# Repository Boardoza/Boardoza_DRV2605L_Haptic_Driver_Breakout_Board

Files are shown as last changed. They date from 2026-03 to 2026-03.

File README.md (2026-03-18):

# Boardoza DRV2605L Haptic Motor Driver Breakout Board

The **Boardoza DRV2605L Haptic Driver Breakout Board** is based on the **Texas Instruments DRV2605L**, a powerful and intelligent haptic motor driver designed specifically for **ERM (Eccentric Rotating Mass)** and **LRA (Linear Resonant Actuator)** vibration motors. Unlike simple on/off motor drivers, the DRV2605L integrates a built-in waveform library and smart-loop control engine to generate advanced vibration effects such as clicks, double-clicks, ramps, buzz patterns, and audio-synchronized feedback.

Unlike standard motor drivers for DC or stepper motors, the DRV2605 is optimized for **ERM (Eccentric Rotating Mass)** and **LRA (Linear Resonant Actuator)** motors. It communicates via **I²C**, allowing you to configure, chain, and trigger complex vibration patterns directly from your microcontroller. This breakout board is ideal for **wearables, game controllers, touch interfaces, mobile devices, assistive systems, and any project that requires professional-grade haptic feedback**.

## [Click here to purchase!](https://www.ozdisan.com/ureticiler/boardoza)

| Front Side | Back Side |
|:---:|:---:|
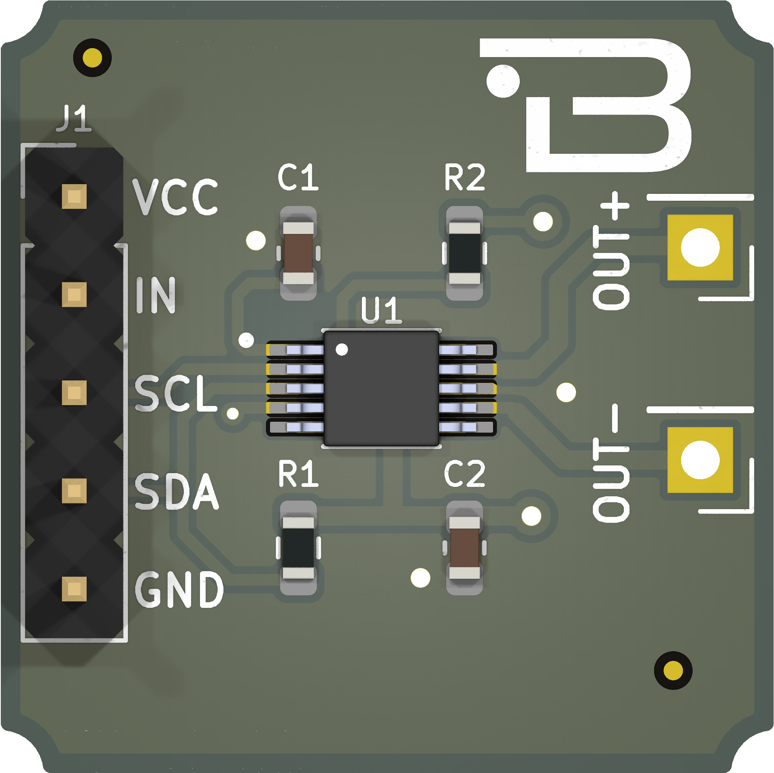
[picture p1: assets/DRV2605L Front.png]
DRV2605L Front
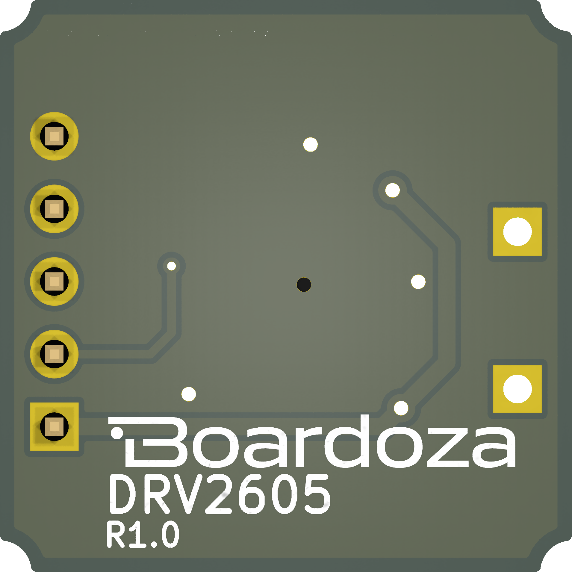
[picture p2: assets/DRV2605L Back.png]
DRV2605L Back
|  |  |

---

## Key Features
 
- **I²C-Controlled Digital Playback Engine:** Includes a waveform sequencer for flexible haptic pattern generation.  
- **Real-Time Playback Options:** Supports control via I²C, PWM, or analog input.  
- **Dual Drive Modes:** Operates in open-loop (ERM) and closed-loop (LRA) configurations.  
- **Smart-Loop™ Control:** Provides automatic overdrive and braking for optimized performance.  
- **Automatic Resonance Tracking:** Includes actuator diagnostics for LRA operation.  
- **Automatic Level Calibration:** Ensures consistent output performance.  
- **Battery Voltage Compensation:** Maintains stable operation under varying supply conditions.  
- **Differential H-Bridge Output:** Features OUT+ and OUT− for driving actuators.    

---

## Technical Specifications

**Model:** DRV2605L  
**Manufacturer:** Boardoza  
**Manufacturer IC:** Texas Instruments  
**Device Type:** Haptic Driver IC  
**Functions:** Smart Haptic Motor Driver    
**Input Voltage (VDD):** 2.0V – 5.2V  
**Interface:** I²C (Standard & Fast Mode, up to 400kHz)  
**Control Input (IN/TRIG):** PWM / Analog / External Trigger (Selectable)  
**Supported Actuators:**  
- ERM (Eccentric Rotating Mass) – Open-Loop Drive  
- LRA (Linear Resonant Actuator) – Closed-Loop with Auto Resonance Tracking  

**Playback Modes:**  
- Internal ROM Waveform Library  
- RAM-Based Custom Waveform Sequencing  
- Real-Time Playback (RTP) Mode  
- Audio-to-Vibe Mode  

**Drive Output:** Differential H-Bridge (OUT+, OUT−)  
**Auto Features:**  
- Automatic Overdrive & Braking  
- Automatic Resonance Tracking (LRA)  
- Automatic Level Calibration  
- Actuator Diagnostics  

**Operating Temperature:** -40°C to +150°C  
**Board Dimensions:** 20mm x 20mm   

---

## Board Pinout

### ( J1 ) Control & Power Connector

| Pin Number | Pin Name | Description |
|:---:|:---:|---|
| 1 | VCC | Supply Input (2.0V – 5.2V DC) |
| 2 | IN | Multi-mode Input (PWM / Analog / Trigger). Connect to GND if unused |
| 3 | SCL | I²C Serial Clock |
| 4 | SDA | I²C Serial Data |
| 5 | GND | Ground |

### ( J2 ) Haptic Motor Output

| Pin Number | Pin Name | Description |
|:---:|:---:|---|
| 1 | OUT+ | Positive Differential Output |
| 2 | OUT− | Negative Differential Output |

---

## Board Dimensions

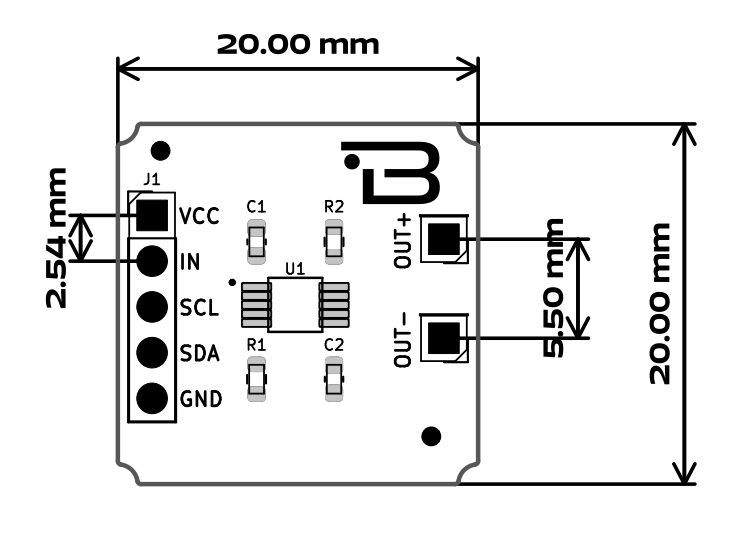
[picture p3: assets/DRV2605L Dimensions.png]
DRV2605L Board Dimension


---

## Step Files

[Boardoza DRV2605L.step](./assets/DRV2605L%20Step.step)

---

## Datasheet

[DRV2605L Datasheet.pdf](./assets/DRV2605L%20Datasheet.pdf)

---

## Version History

- V1.0.0 - Initial Release  

---

## Support

- If you have any questions or need support, please contact **support@boardoza.com**

---

## **License**

This repository contains both hardware and software components:

### **Hardware Design**

[][cc-by-sa]

All hardware design files are licensed under [Creative Commons Attribution-ShareAlike 4.0 International License][cc-by-sa].

[cc-by-sa]: http://creativecommons.org/licenses/by-sa/4.0/
[cc-by-sa-shield]: https://img.shields.io/badge/License-CC%20BY--SA%204.0-lightgrey.svg

### **Software/Firmware**

[][bsd]

All software and firmware are licensed under [BSD 3-Clause License][bsd].

[bsd]: https://opensource.org/licenses/BSD-3-Clause
[bsd-shield]: https://img.shields.io/badge/License-BSD%203--Clause-blue.svg

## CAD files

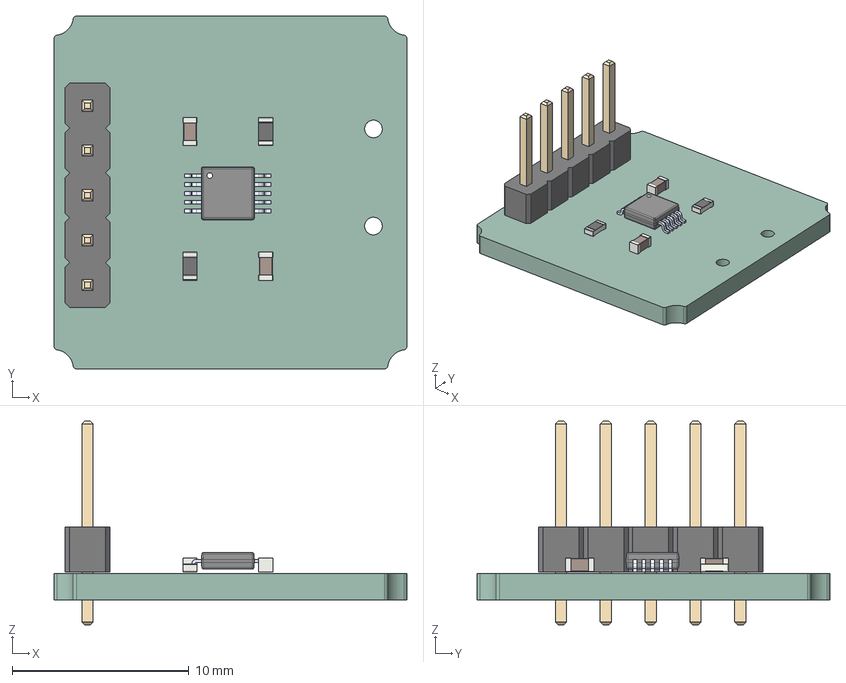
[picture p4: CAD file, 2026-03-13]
assets/DRV2605L Step.step
20.0 x 20.0 x 11.5 mm
PinHeader_1x05_P2.54mm_Vertical
R_0603_1608Metric x 2
C_0603_1608Metric x 2
DRV2605LDGSR
B-DRV2605L-BRK_PCB

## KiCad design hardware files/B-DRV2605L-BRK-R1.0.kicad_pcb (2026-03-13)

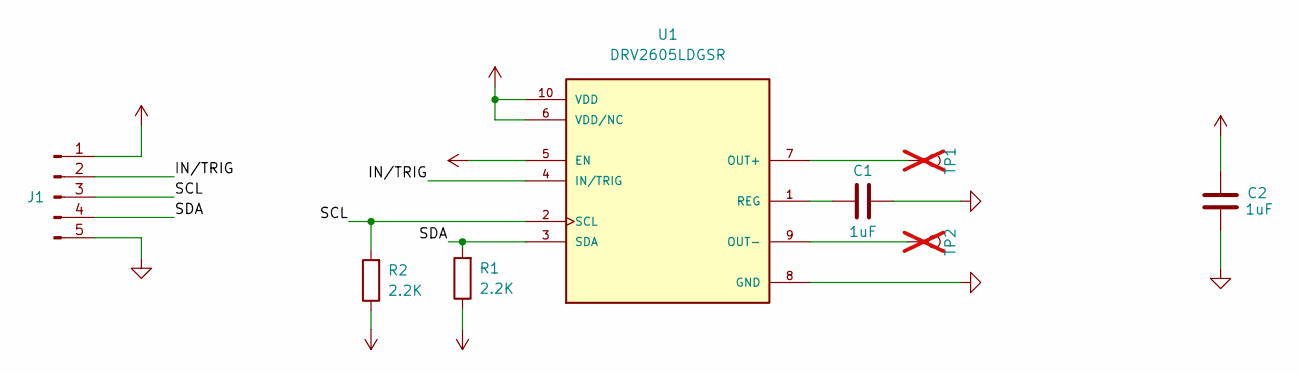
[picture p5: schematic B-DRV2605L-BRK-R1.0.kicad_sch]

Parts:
C1, C2: 1uF; C_0603_1608Metric; MPN CL10A105KO8NNNC
J1: Conn_01x05_Pin; PinHeader_1x05_P2.54mm_Vertical; MPN 5PH1SDA25-105G0NNBL-3X6
R1, R2: 2.2K; R_0603_1608Metric; MPN CRT03F7E2201
TP1, TP2: TestPoint; PinHeader_1x01_P2.54mm_Vertical; not fitted
U1: DRV2605LDGSR; SOP50P490X110-10N; PARTREV D

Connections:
/IN/TRIG: J1.2, U1.4 (IN/TRIG)
/SCL: J1.3, R2.2, U1.2 (SCL)
/SDA: J1.4, R1.2, U1.3 (SDA)
GND: C1.2, C2.1, J1.5, U1.8 (GND)
unnamed: TP1.1, U1.7 (OUT+)
unnamed: TP2.1, U1.9 (OUT-)
unnamed: C1.1, U1.1 (REG)
VCC: C2.2, J1.1, R1.1, R2.1, U1.5 (EN), U1.6 (VDD/NC), U1.10 (VDD)

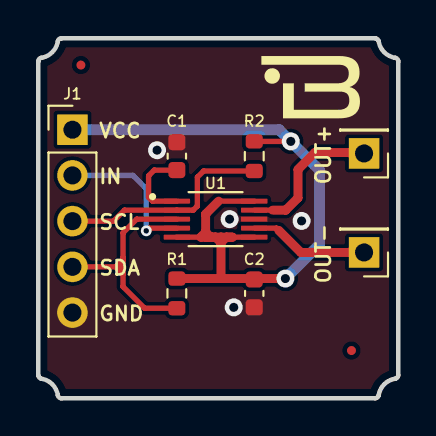
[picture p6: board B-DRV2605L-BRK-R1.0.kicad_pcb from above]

Board: 2 copper layers, 20.0 x 20.0 mm, 8 parts (0 on the bottom side), 8 nets.

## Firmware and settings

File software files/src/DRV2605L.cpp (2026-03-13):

#include "DRV2605L.h"

/**
 * @brief Default constructor for the DRV2605L class.
 *
 * Initializes the I2C address with the default DRV2605L I2C address
 * and sets the I2C interface pointer to nullptr.
 */
DRV2605L::DRV2605L() {
  _i2c = nullptr;
  _i2cAddr = DRV2605L_I2C_ADDR;
}

/**
 * @brief Initializes the DRV2605L device.
 *
 * This function initializes the I2C communication with the specified I2C interface
 * and sets the device's I2C address. It also performs basic setup such as
 * reading the status register, setting the mode to auto-calibration, and 
 * selecting the waveform library.
 *
 * @param wirePort Reference to the TwoWire I2C object (Wire or Wire1).
 * @param i2cAddr  The I2C address of the DRV2605L device.
 * @return true if initialization is successful.
 */
bool DRV2605L::begin(TwoWire &wirePort, uint8_t i2cAddr) {
  _i2c = &wirePort;
  _i2cAddr = i2cAddr;

  _i2c->begin();

  uint8_t status = readRegister8(DRV2605L_REG_STATUS);

  writeRegister8(DRV2605L_REG_MODE, DRV2605L_MODE_AUTOCAL);

  writeRegister8(DRV2605L_REG_LIBRARY, 0x06);

  return true;
}

/**
 * @brief Sets the operating mode of the DRV2605L.
 *
 * The DRV2605L supports multiple modes such as standby, real-time playback, 
 * and auto-calibration. This function sets the mode by writing to the mode register.
 *
 * @param mode The desired operating mode (0-7).
 */
void DRV2605L::setMode(uint8_t mode) {
  writeRegister8(DRV2605L_REG_MODE, mode & 0x07);
}

/**
 * @brief Writes an 8-bit value to a specified register of the DRV2605L.
 *
 * This function sends a command via I2C to write a given value to a specific 
 * register of the DRV2605L haptic driver.
 *
 * @param reg The register address to write to.
 * @param val The 8-bit value to be written to the register.
 */
void DRV2605L::writeRegister8(uint8_t reg, uint8_t val) {
  _i2c->beginTransmission(_i2cAddr);
  _i2c->write(reg);
  _i2c->write(val);
  _i2c->endTransmission();
}

/**
 * @brief Reads an 8-bit value from a specified register of the DRV2605L.
 *
 * This function requests a single byte from the specified register
 * of the DRV2605L over the I2C bus.
 *
 * @param reg The register address to read from.
 * @return The 8-bit value read from the register. Returns 0 if no data is available.
 */
uint8_t DRV2605L::readRegister8(uint8_t reg) {
  _i2c->beginTransmission(_i2cAddr);
  _i2c->write(reg);
  _i2c->endTransmission(false);

  _i2c->requestFrom((int)_i2cAddr, 1);
  if (_i2c->available()) {
    return _i2c->read();
  }
  return 0;
}

/**
 * @brief Sets a waveform sequence slot in the DRV2605L.
 *
 * The DRV2605L supports up to 8 waveform slots, each storing a waveform effect. 
 * This function assigns a waveform to a specific slot, defining the sequence 
 * of haptic effects to be played.
 *
 * @param slot The waveform sequence slot (1-8).
 * @param waveform The waveform ID to assign to the slot.
 */
void DRV2605L::setWaveform(uint8_t slot, uint8_t waveform) {
  // slot = 1 -> 0x04 (WAVESEQ1)
  // slot = 2 -> 0x05 (WAVESEQ2), vb.
  // Basitçe: 0x04 + (slot - 1)
  if(slot < 1) slot = 1;
  if(slot > 8) slot = 8; // Maksimum 8 slot var
  writeRegister8(DRV2605L_REG_WAVESEQ1 + slot - 1, waveform);
}

/**
 * @brief Starts haptic playback.
 *
 * This function sets the GO bit (bit 0) in the DRV2605L control register
 * to initiate haptic playback using the configured waveform sequence.
 */
void DRV2605L::go() {
  writeRegister8(DRV2605L_REG_GO, 0x01);
}

/**
 * @brief Stops haptic playback.
 *
 * This function clears the GO bit (bit 0) in the DRV2605L control register,
 * stopping any currently playing haptic effects.
 */
void DRV2605L::stop() {
  writeRegister8(DRV2605L_REG_GO, 0x00);
}

/**
 * @brief Sets the real-time playback (RTP) value.
 *
 * The real-time playback feature allows direct control of the actuator
 * output by writing an 8-bit value to the RTP register. The RTP mode must 
 * be enabled beforehand.
 *
 * @param rtpVal The 8-bit RTP value (0-255) to control actuator strength.
 */
void DRV2605L::setRealtimeValue(uint8_t rtpVal) {
  writeRegister8(DRV2605L_REG_RTP_IN, rtpVal);
}

/**
 * @brief Sets the rated voltage for the actuator.
 *
 * This function sets the rated voltage register, which defines the normal 
 * operating voltage for the actuator. It is used during automatic calibration 
 * to optimize the output drive.
 *
 * @param val The 8-bit rated voltage value.
 */
void DRV2605L::setRatedVoltage(uint8_t val) {
  writeRegister8(DRV2605L_REG_RATEDV, val);
}

/**
 * @brief Sets the overdrive clamp voltage.
 *
 * The overdrive clamp voltage defines the maximum allowable voltage applied 
 * during the overdrive phase of haptic playback. This setting can affect 
 * the intensity and duration of effects.
 *
 * @param val The 8-bit overdrive clamp voltage value.
 */
void DRV2605L::setOverdriveClampVoltage(uint8_t val) {
  writeRegister8(DRV2605L_REG_CLAMPV, val);
}
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

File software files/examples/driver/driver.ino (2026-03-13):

#include <Wire.h>
#include "DRV2605L.h"

DRV2605L haptic;  // Create an instance of the DRV2605L class

void setup() {
  Serial.begin(115200);
  delay(100);

  // Initialize the library
  // If using an alternative TwoWire instance (e.g., Wire1), replace Wire accordingly
  if(!haptic.begin(Wire, 0x5A)) {
    Serial.println("DRV2605L connection failed!");
    while(1);
  }
  Serial.println("DRV2605L initialized.");

  // Example: Perform automatic calibration
  if(!haptic.autoCalibrate(0x50, 0x80)) {
    Serial.println("Auto calibration failed or timed out.");
  } else {
    Serial.println("Auto calibration successful.");
  }

  // LRA or ERM settings:
  // Configure RATED VOLTAGE and CLAMP VOLTAGE according to your haptic motor's datasheet.
  // Example:
  // haptic.setRatedVoltage(0x50);      // ~ 1.8V
  // haptic.setOverdriveClampVoltage(0x80);  // ~ 3.6V

  // Set to internal trigger mode (MODE 0)
  haptic.setMode(DRV2605L_MODE_INTTRIG);

  // Define waveform sequence (effects stored in ROM)
  // Example: Assign effect ID 1 to slot 1, and 0 (end) to slot 2
  haptic.setWaveform(1, 1);   // Slot 1: ROM effect ID = 1
  haptic.setWaveform(2, 0);   // Slot 2: 0 => end
}

void loop() {
  Serial.println("Playing effect...");
  haptic.go();    // Start waveform sequence
  delay(1000);    // Wait until the effect completes (duration depends on effect length)

  // To replay the effect, wait and call go() again
  delay(1000);
}

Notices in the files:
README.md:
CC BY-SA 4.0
